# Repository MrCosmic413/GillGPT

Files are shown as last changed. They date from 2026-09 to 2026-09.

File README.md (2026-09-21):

# GillGPT — Meet Kevin 🐟

Kevin is an AI-powered animatronic fish built by modifying a Big Mouth Billy Bass. GillGPT brings together conversational AI, speech recognition, synthesized speech, a Raspberry Pi, FPGA motor control, and a custom KiCad PCB.

The project has grown from reverse-engineering two motors into an integrated hardware/software build: Kevin speaks, moves his mouth with the audio, and shows activity on an LCD.

## How it works

```text
Microphone → Raspberry Pi / KevinOS → PC speech recognition
                        ↓
                   Ollama response
                        ↓
                  Kokoro speech → Speaker
                        ↓
              Mouth animation + LCD feedback
                        ↓
       UART → Tang Nano 9K FPGA → TB6612FNG → Motors
```

The Raspberry Pi coordinates the interaction. The PC provides AI and speech services. The Tang Nano 9K handles timed motor sequences in Verilog, with the TB6612FNG driving the mouth and shared head/tail mechanism.

## Build status — September 20, 2026

- Original mechanism reverse engineered; motor direction and wiring documented.
- Custom KiCad schematic, PCB layout, and module footprints added.
- FPGA UART, PWM, mouth animation, head return, tail movement, and stop command implemented in source.
- Voice, LCD feedback, and mouth movement reported working in the latest integration session.
- Head/tail motor interference remains under investigation: disconnecting J3 restored clean audio in the latest test. The precise electrical cause and final fix still need verification.
- Full completion video will be added after the remaining fixes and final demonstration.

**Source coverage:** the FPGA and hardware files are recovered from the local project. PC service source is included. The available Pi backup is dated **August 19, 2026** and is preserved as an explicitly dated snapshot; it does **not** contain all September changes or the latest LCD integration. See [source provenance and outstanding work](docs/STATUS.md).

## Explore the project

| Area | Files |
| --- | --- |
| Editable schematic and PCB | [KiCad project](hardware/kicad/Kevin_PCB.kicad_pro), [schematic](hardware/kicad/Kevin_PCB.kicad_sch), [PCB](hardware/kicad/Kevin_PCB.kicad_pcb) |
| Custom module footprints | [Kevin.pretty](hardware/kicad/Kevin.pretty) |
| Manufacturing exports | [Saved Gerber sets](hardware/fabrication) |
| Main FPGA controller | [Verilog](firmware/Kevin_motor_controller/src/kevin_motor_controller.v), [pin constraints](firmware/Kevin_motor_controller/src/kevin_motor_controller.cst), [Gowin project](firmware/Kevin_motor_controller/Kevin_motor_controller.gprj) |
| Earlier FPGA bring-up | [Mouth test](firmware/Kevin_motor_test), [UART](firmware/kevin_nano_uart), [LED blink](firmware/kevin_nano_blink) |
| PC voice and integration services | [PC software](software/pc) |
| Historical Pi code | [KevinOS — August 19 snapshot](software/archive/2026-08-19/KevinOS) |
| Original motor investigation | [Reverse-engineering notes](docs/REV001_ReverseEngineering.md) |

## Hardware and firmware

Open `hardware/kicad/Kevin_PCB.kicad_pro` in KiCad. Keep `Kevin.pretty` and `fp-lib-table` alongside the project so its custom footprints resolve. Saved fabrication exports are historical sets; their correspondence to the current board has not been verified. Regenerate fabrication files from a checked board before ordering.

Open the main controller `.gprj` in Gowin for the Tang Nano 9K. Source defaults assume a 27 MHz clock, approximately 115200-baud UART, and 1 kHz PWM. Motor timing and duty-cycle constants are specific to this mechanism.

| UART byte | Action |
| --- | --- |
| `q`, `n`, `N`, `e`, `E` | Quiet, normal short/long, and emphasis short/long mouth sequences |
| `H` | Head out |
| `h` | Head home |
| `T` | Tail sequence |
| `S` | Stop |

Acknowledgements identify recognized commands; they do not prove physical movement completed. The early reverse-engineering notes use motor labels from the original investigation; the main FPGA source calls the mouth channel A and head/tail channel B.

## Software

See [PC service setup](software/pc/README.md). The services cover Kokoro speech synthesis, faster-whisper transcription, and an optional Spotify/file-access bridge. Ollama supplies the language-model endpoint used by KevinOS.

The dated Pi snapshot is useful for understanding the earlier audio, AI, and motor architecture. It is not a complete reproduction of the present build. The current Pi source, dependency versions, and final demonstration remain to be synchronized.

## Validation

For this repository update, Python sources were checked for syntax and the main Verilog controller was compiled with Icarus Verilog. These checks do not establish hardware operation, timing closure, electrical correctness, or completion of the remaining integration fixes.

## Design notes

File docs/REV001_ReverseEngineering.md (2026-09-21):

# REV001 - Reverse Engineering Report

## Device

Big Mouth Billy Bass

---

## Objective

Determine how the original animatronic mechanism operates so that it can be replaced with a Raspberry Pi controller.

---

## Findings

### Motors

Motor A

Wire Colors:
- Orange
- Black

Function:
Head and Tail

Rotation:

Orange + / Black -
Head Movement

Orange - / Black +
Tail Movement

---

Motor B

Wire Colors

- Red
- Grey

Function

Mouth

Rotation

Red + / Grey -
Mouth Opens

Red - / Grey +
Mouth Closes

---

Power

Original Supply

6V

(4 AA Batteries)

---

Controller

Original controller board removed.

Future controller:

Raspberry Pi 4

Motor Driver:

TB6612FNG

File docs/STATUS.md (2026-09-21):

# Source provenance and remaining work

Repository update: September 20, 2026.

- `hardware/kicad`: Kevin_PCB project last saved September 2, including the two custom module footprints and project-relative footprint library table.
- `hardware/fabrication`: the two saved Kevin PCB Gerber/drill sets from the local GillGPT folder. Retained separately; neither is asserted to match the latest KiCad board.
- `firmware`: local Gowin projects and source files, including the main motor controller and earlier experiments. Generated build directories and user-specific IDE files are excluded.
- `software/pc`: recovered PC service scripts. The publishing copy replaces the embedded shared bridge key with `KEVIN_BRIDGE_KEY`, uses portable home-relative folders, and reads Spotify configuration from a local `.env`. A stray bracket and duplicate obsolete file-search/path-check functions in the recovered bridge were removed; the folder-alias-aware implementations are retained. The running PC files were not changed.
- `software/archive/2026-08-19/KevinOS`: Python source recovered from the August 19 Pi backup. Embedded bridge keys were replaced with `KEVIN_BRIDGE_KEY`. Personal conversation memory, OAuth cache, credentials, virtual environments, and generated files are excluded. This is a sanitized historical snapshot, not the September runtime.

## Latest reported integration state

On September 20, voice, LCD behavior, and mouth animation were reported working. Reintroducing the head/body path produced static; unplugging J3 restored clean speech. Motor noise, supply disturbance, and grounding remain candidate causes. A final electrical fix has not been verified in this repository update.

## Needed to finish synchronization

1. Retrieve the current `~/KevinOS` source from the Raspberry Pi, including the LCD code and latest audio/streaming changes.
2. Record the working dependency/model versions and launch configuration.
3. Verify the motor interference fix on hardware and update the status.
4. Add the new full demonstration video after recording it.

No hardware tests or fresh KiCad ERC/DRC were performed during this update. The local historical ERC report predates the final schematic save and is not presented as current validation.

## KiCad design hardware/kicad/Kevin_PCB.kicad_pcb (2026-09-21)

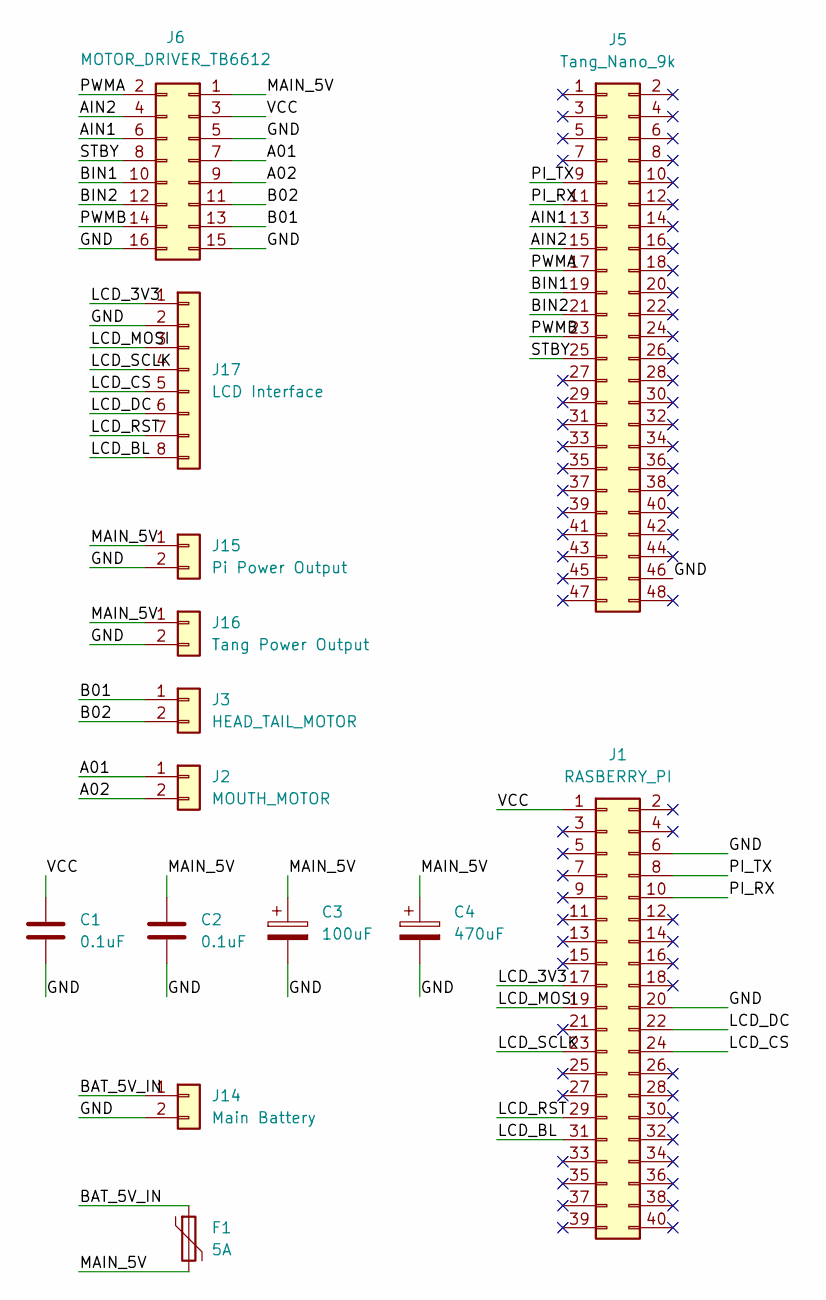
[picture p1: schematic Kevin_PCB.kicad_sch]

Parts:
C1, C2: 0.1uF; C_0805_2012Metric
C3: 100uF; CP_Radial_D6.3mm_P2.50mm
C4: 470uF; CP_Radial_D8.0mm_P3.50mm
F1: 5A; Fuse_Bourns_MF-RG300
J1: RASBERRY_PI; PinSocket_2x20_P2.54mm_Vertical
J2: MOUTH_MOTOR; TerminalBlock_Phoenix_MKDS-1,5-2-5.08_1x02_P5.08mm_Horizont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
J3: HEAD_TAIL_MOTOR; TerminalBlock_Phoenix_MKDS-1,5-2-5.08_1x02_P5.08mm_Horizont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
J5: Tang_Nano_9k; Tang_Nano_9K_Module
J6: MOTOR_DRIVER_TB6612; TB6612_Module_2x8_15mm
J14: Main Battery; TerminalBlock_Phoenix_MKDS-1,5-2-5.08_1x02_P5.08mm_Horizont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
J15: Pi Power Output; TerminalBlock_Phoenix_MKDS-1,5-2-5.08_1x02_P5.08mm_Horizont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
J16: Tang Power Output; TerminalBlock_Phoenix_MKDS-1,5-2-5.08_1x02_P5.08mm_Horizont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
J17: LCD Interface; PinHeader_1x08_P2.54mm_Vertical

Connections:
/A01: J2.1, J6.7
/A02: J2.2, J6.9
/AIN1: J5.13, J6.6
/AIN2: J5.15, J6.4
/B01: J3.1, J6.13
/B02: J3.2, J6.11
/BAT_5V_IN: F1.1, J14.1
/BIN1: J5.19, J6.10
/BIN2: J5.21, J6.12
/GND: C1.2, C2.2, C3.2, C4.2, J1.6, J1.20, J5.46, J6.5, J6.15, J6.16, J14.2, J15.2, J16.2, J17.2
/LCD_3V3: J1.17, J17.1
/LCD_BL: J1.31, J17.8
/LCD_CS: J1.24, J17.5
/LCD_DC: J1.22, J17.6
/LCD_MOSI: J1.19, J17.3
/LCD_RST: J1.29, J17.7
/LCD_SCLK: J1.23, J17.4
/MAIN_5V: C2.1, C3.1, C4.1, F1.2, J6.1, J15.1, J16.1
/PI_RX: J1.10, J5.11
/PI_TX: J1.8, J5.9
/PWMA: J5.17, J6.2
/PWMB: J5.23, J6.14
/STBY: J5.25, J6.8
/VCC: C1.1, J1.1, J6.3

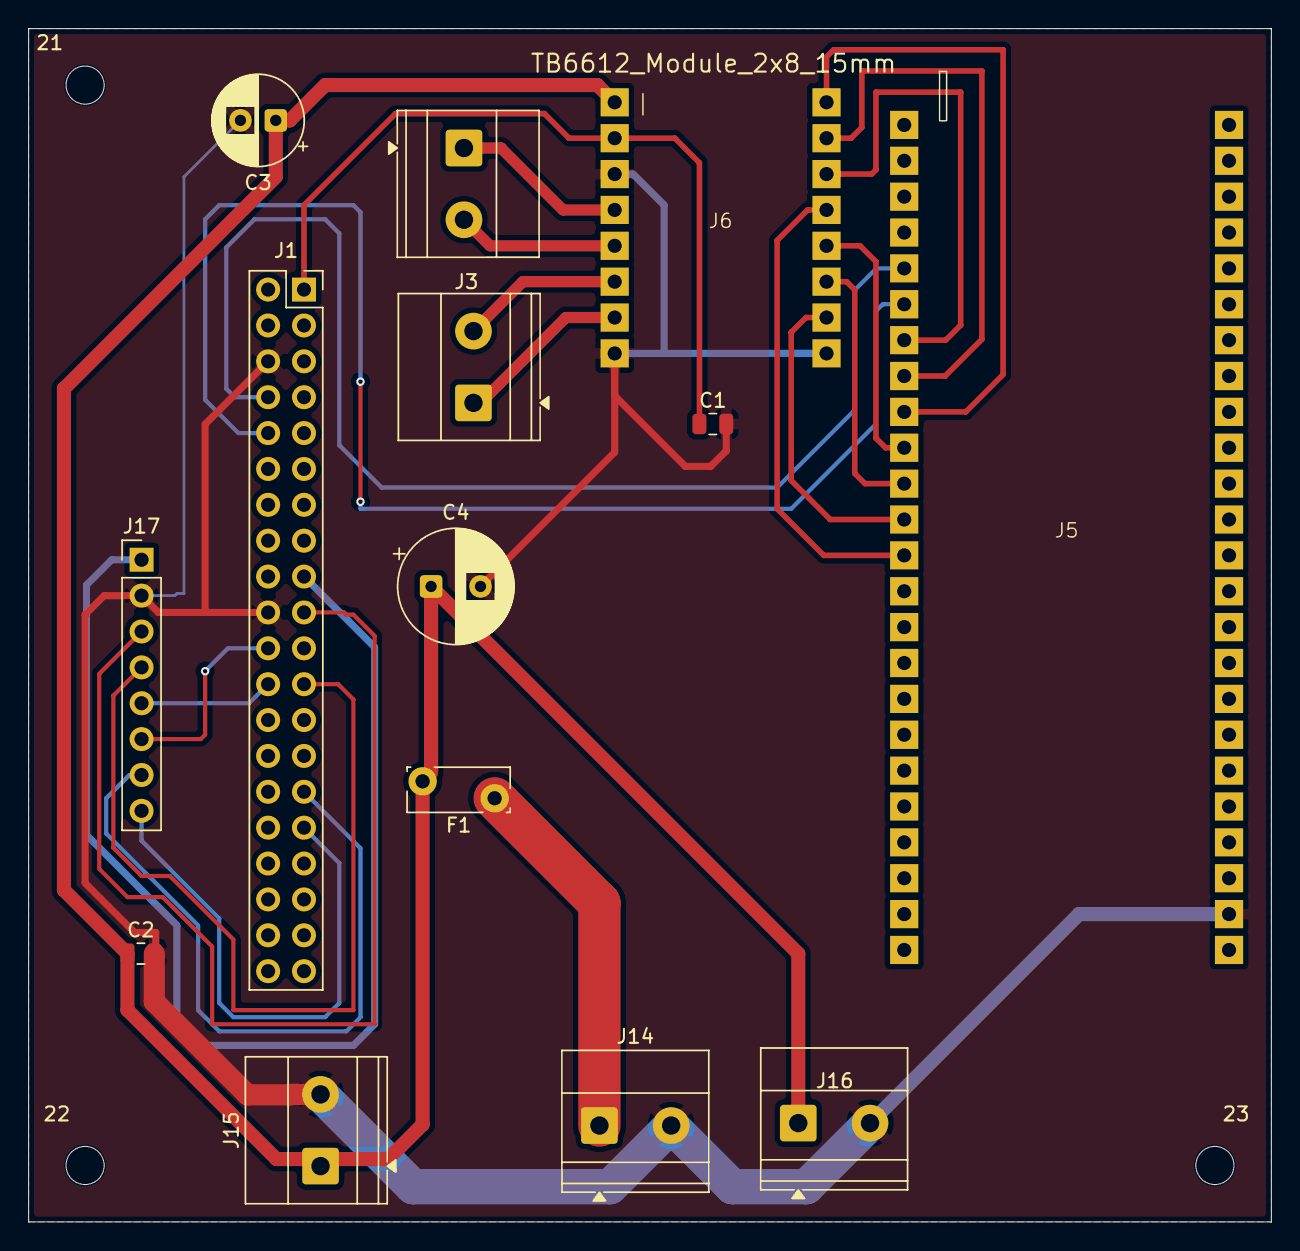
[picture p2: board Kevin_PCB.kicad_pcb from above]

Board: 2 copper layers, 88.0 x 84.5 mm, 17 parts (0 on the bottom side), 24 nets.

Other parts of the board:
21, 22, 23: MountingHole_2.7mm_M2.5

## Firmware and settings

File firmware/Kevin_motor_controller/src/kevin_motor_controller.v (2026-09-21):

module kevin_motor_controller (
    input clk,
    input uart_rx,

    output reg uart_tx,

    // Mouth / Motor A
    output reg ain1,
    output reg ain2,
    output pwma,

    // Head + Tail / Motor B
    output reg bin1,
    output reg bin2,
    output pwmb,

    // TB6612 enable
    output reg stby
);

    // =====================================================
    // CLOCK / UART SETTINGS
    // =====================================================

    parameter CLKS_PER_BIT = 234;

    // 27 MHz / 27000 = 1 kHz PWM
    parameter PWM_PERIOD = 27000;


    // =====================================================
    // KEVIN CALIBRATION
    // =====================================================



    // -----------------------------------------------------
    // MOUTH TIMINGS
    // -----------------------------------------------------

    // Quiet speech
    localparam MOUTH_QUIET_OPEN  = 1620000; // 0.060 s
    localparam MOUTH_QUIET_CLOSE = 2025000; // 0.075 s

    // Normal short
    localparam MOUTH_NORMAL_SHORT_OPEN  = 2160000; // 0.080 s
    localparam MOUTH_NORMAL_SHORT_CLOSE = 1755000; // 0.065 s

    // Normal long
    localparam MOUTH_NORMAL_LONG_OPEN  = 3375000; // 0.125 s
    localparam MOUTH_NORMAL_LONG_CLOSE = 2160000; // 0.080 s

    // Emphasis fast
    localparam MOUTH_EMPH_FAST_OPEN  = 2565000; // 0.095 s
    localparam MOUTH_EMPH_FAST_CLOSE = 1485000; // 0.055 s

    // Emphasis long
    localparam MOUTH_EMPH_LONG_OPEN  = 3645000; // 0.135 s
    localparam MOUTH_EMPH_LONG_CLOSE = 2025000; // 0.075 s

    localparam MOUTH_PWM = 21600;            // 80%
    localparam BODY_PWM = 20250;             // 75%
    localparam HEAD_HOME_MAIN_PWM = 20250;   // 75%
    localparam HEAD_HOME_FINAL_PWM = 12150;  // 45%


    // -----------------------------------------------------
    // HEAD TIMINGS
    // -----------------------------------------------------

    localparam HEAD_OUT_TIME =
        18900000; // 0.70 s

    localparam HEAD_HOME_MAIN_TIME =
        12420000; // 0.46 s

    localparam HEAD_HOME_SETTLE_TIME =
        2700000; // 0.10 s

    localparam HEAD_HOME_FINAL_TIME =
        1080000; // 0.04 s


    // -----------------------------------------------------
    // TAIL TIMINGS
    // -----------------------------------------------------

    localparam TAIL_OUT_TIME =
        14850000; // 0.55 s

    localparam TAIL_SPRING_WAIT =
        4050000; // 0.15 s

    localparam TAIL_RESET_TIME =
        8100000; // 0.30 s


    // =====================================================
    // UART RX STATES
    // =====================================================

    localparam RX_IDLE  = 3'd0;
    localparam RX_START = 3'd1;
    localparam RX_DATA  = 3'd2;
    localparam RX_STOP  = 3'd3;


    // =====================================================
    // UART TX STATES
    // =====================================================

    localparam TX_IDLE  = 3'd0;
    localparam TX_START = 3'd1;
    localparam TX_DATA  = 3'd2;
    localparam TX_STOP  = 3'd3;


    // =====================================================
    // MOUTH STATES
    // =====================================================

    localparam MOUTH_IDLE  = 2'd0;
    localparam MOUTH_OPEN  = 2'd1;
    localparam MOUTH_CLOSE = 2'd2;


    // =====================================================
    // BODY STATES
    // =====================================================

    localparam BODY_HOME =
        4'd0;

    localparam BODY_HEAD_OUT_MOVING =
        4'd1;

    localparam BODY_HEAD_OUT =
        4'd2;

    localparam BODY_HEAD_HOME_MAIN =
        4'd3;

    localparam BODY_HEAD_HOME_SETTLE =
        4'd4;

    localparam BODY_HEAD_HOME_FINAL =
        4'd5;

    localparam BODY_TAIL_OUT =
        4'd6;

    localparam BODY_TAIL_WAIT =
        4'd7;

    localparam BODY_TAIL_RESET =
        4'd8;


    // =====================================================
    // UART RX REGISTERS
    // =====================================================

    reg [2:0] rx_state = RX_IDLE;

    reg [8:0] rx_clock_count = 0;
    reg [2:0] rx_bit_index = 0;

    reg [7:0] received_byte = 0;

    reg rx_meta = 1'b1;
    reg rx_sync = 1'b1;

    // One-clock pulse saying:
    // "A command has arrived."
    reg command_valid = 1'b0;

    reg [7:0] command_byte = 0;


    // =====================================================
    // UART TX REGISTERS
    // =====================================================

    reg [2:0] tx_state = TX_IDLE;

    reg [8:0] tx_clock_count = 0;
    reg [2:0] tx_bit_index = 0;

    reg [7:0] tx_byte = 0;

    reg response_valid = 1'b0;
    reg [7:0] response_byte = 0;


    // =====================================================
    // PWM REGISTERS
    // =====================================================

    reg [15:0] pwm_counter = 0;

    reg [15:0] mouth_pwm_duty = 0;
    reg [15:0] body_pwm_duty = 0;

    reg mouth_pwm_enable = 1'b0;
    reg body_pwm_enable = 1'b0;


    assign pwma =
        mouth_pwm_enable &&
        (pwm_counter < mouth_pwm_duty);

    assign pwmb =
        body_pwm_enable &&
        (pwm_counter < body_pwm_duty);


    always @(posedge clk) begin

        if (pwm_counter >= PWM_PERIOD - 1)
            pwm_counter <= 0;

        else
            pwm_counter <= pwm_counter + 1'b1;

    end


    // =====================================================
    // UART INPUT SYNCHRONIZER
    // =====================================================

    always @(posedge clk) begin

        rx_meta <= uart_rx;
        rx_sync <= rx_meta;

    end


    // =====================================================
    // UART RECEIVER
    // =====================================================

    always @(posedge clk) begin

        command_valid <= 1'b0;


        case (rx_state)

            // -------------------------------------------------
            // IDLE
            // -------------------------------------------------

            RX_IDLE: begin

                rx_clock_count <= 0;
                rx_bit_index <= 0;

                if (rx_sync == 1'b0)
                    rx_state <= RX_START;

            end


            // -------------------------------------------------
            // START BIT
            // -------------------------------------------------

            RX_START: begin

                if (
                    rx_clock_count ==
                    CLKS_PER_BIT / 2
                ) begin

                    rx_clock_count <= 0;

                    if (rx_sync == 1'b0)
                        rx_state <= RX_DATA;

                    else
                        rx_state <= RX_IDLE;

                end

                else begin

                    rx_clock_count <=
                        rx_clock_count + 1'b1;

                end

            end
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

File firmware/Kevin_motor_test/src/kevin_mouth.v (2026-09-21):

module kevin_nano_motor (
    input clk,
    input uart_rx,
    output reg uart_tx,

    output reg ain1,
    output reg ain2,
    output pwma,
    output reg stby
);

    // =====================================================
    // CLOCK / UART
    // =====================================================

    parameter CLKS_PER_BIT = 234;

    // 1 kHz PWM
    // 27 MHz / 27000 = 1000 Hz
    parameter PWM_PERIOD = 27000;

    // 40% duty cycle
    parameter PWM_DUTY = 10800;

    // About 70 ms at 27 MHz
    parameter MOTOR_TIME = 1890000;


    // =====================================================
    // UART RX STATES
    // =====================================================

    localparam RX_IDLE  = 3'd0;
    localparam RX_START = 3'd1;
    localparam RX_DATA  = 3'd2;
    localparam RX_STOP  = 3'd3;


    // =====================================================
    // UART TX STATES
    // =====================================================

    localparam TX_IDLE  = 3'd0;
    localparam TX_START = 3'd1;
    localparam TX_DATA  = 3'd2;
    localparam TX_STOP  = 3'd3;


    // =====================================================
    // MOTOR STATES
    // =====================================================

    localparam MOTOR_IDLE  = 2'd0;
    localparam MOTOR_OPEN  = 2'd1;
    localparam MOTOR_CLOSE = 2'd2;


    // =====================================================
    // UART RX REGISTERS
    // =====================================================

    reg [2:0] rx_state = RX_IDLE;

    reg [8:0] rx_clock_count = 0;
    reg [2:0] rx_bit_index = 0;

    reg [7:0] received_byte = 0;

    reg rx_meta = 1'b1;
    reg rx_sync = 1'b1;

    reg rx_valid = 1'b0;

    reg [7:0] response_byte = 0;


    // =====================================================
    // UART TX REGISTERS
    // =====================================================

    reg [2:0] tx_state = TX_IDLE;

    reg [8:0] tx_clock_count = 0;
    reg [2:0] tx_bit_index = 0;

    reg [7:0] tx_byte = 0;


    // =====================================================
    // COMMAND PULSES
    // =====================================================

    reg command_open  = 1'b0;
    reg command_close = 1'b0;
    reg command_stop  = 1'b0;


    // =====================================================
    // PWM
    // =====================================================

    reg [15:0] pwm_counter = 0;

    reg pwm_enable = 1'b0;

    assign pwma =
        pwm_enable &&
        (pwm_counter < PWM_DUTY);


    always @(posedge clk) begin

        if (pwm_counter >= PWM_PERIOD - 1)
            pwm_counter <= 0;
        else
            pwm_counter <= pwm_counter + 1'b1;

    end


    // =====================================================
    // MOTOR CONTROL
    // =====================================================

    reg [1:0] motor_state = MOTOR_IDLE;

    reg [20:0] motor_timer = 0;


    always @(posedge clk) begin

        // ---------------------------------------------
        // Immediate STOP command
        // ---------------------------------------------

        if (command_stop) begin

            motor_state <= MOTOR_IDLE;

            ain1 <= 1'b0;
            ain2 <= 1'b0;

            pwm_enable <= 1'b0;

            motor_timer <= 0;

        end

        else begin

            case (motor_state)

                // =========================================
                // IDLE
                // =========================================

                MOTOR_IDLE: begin

                    ain1 <= 1'b0;
                    ain2 <= 1'b0;

                    pwm_enable <= 1'b0;

                    motor_timer <= 0;

                    if (command_open) begin

                        motor_state <= MOTOR_OPEN;

                    end

                    else if (command_close) begin

                        motor_state <= MOTOR_CLOSE;

                    end

                end


                // =========================================
                // OPEN
                // =========================================

                MOTOR_OPEN: begin

                    ain1 <= 1'b0;
                    ain2 <= 1'b1;

                    pwm_enable <= 1'b1;

                    if (
                        motor_timer >= MOTOR_TIME - 1
                    ) begin

                        motor_timer <= 0;

                        motor_state <= MOTOR_IDLE;

                    end

                    else begin

                        motor_timer <=
                            motor_timer + 1'b1;

                    end

                end


                // =========================================
                // CLOSE
                // =========================================

                MOTOR_CLOSE: begin

                    ain1 <= 1'b1;
                    ain2 <= 1'b0;

                    pwm_enable <= 1'b1;

                    if (
                        motor_timer >= MOTOR_TIME - 1
                    ) begin

                        motor_timer <= 0;

                        motor_state <= MOTOR_IDLE;

                    end

                    else begin

                        motor_timer <=
                            motor_timer + 1'b1;

                    end

                end


                // =========================================
                // DEFAULT
                // =========================================

                default: begin

                    motor_state <= MOTOR_IDLE;

                end

            endcase

        end

    end


    // =====================================================
    // UART INPUT SYNCHRONIZER
    // =====================================================

    always @(posedge clk) begin

        rx_meta <= uart_rx;
        rx_sync <= rx_meta;

    end


    // =====================================================
    // UART RECEIVER
    // =====================================================

    always @(posedge clk) begin

        // These pulses are normally LOW.
        // They go HIGH for exactly one clock cycle
        // when the matching command arrives.

        command_open  <= 1'b0;
        command_close <= 1'b0;
        command_stop  <= 1'b0;

        rx_valid <= 1'b0;


        case (rx_state)

            // =========================================
            // IDLE
            // =========================================

            RX_IDLE: begin

                rx_clock_count <= 0;
                rx_bit_index <= 0;

                if (rx_sync == 1'b0)
                    rx_state <= RX_START;

            end


            // =========================================
            // START BIT
            // =========================================

            RX_START: begin

                if (
                    rx_clock_count ==
                    CLKS_PER_BIT / 2
                ) begin
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

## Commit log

2026-08-02 Initialize GillGPT Raspberry Pi project
2026-09-21 Document Kevin build and add hardware firmware and recovered software
    [Kevin_PCB-B_Cu.gbr, Kevin_PCB-B_Mask.gbr, Kevin_PCB-B_Silkscreen.gbr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]
